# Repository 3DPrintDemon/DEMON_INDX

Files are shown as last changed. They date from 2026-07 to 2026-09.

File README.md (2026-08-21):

# INDX Wiki

> The community knowledge base for the Bondtech INDX, an induction-based automatic tool changer for open-platform XY-head 3D printers.

---

## Table of Contents

**Part 1: What is INDX?**

1. [What is INDX?](#what-is-indx)
2. [How It Works](#how-it-works)
3. [Kits & What's in the Box](#kits--whats-in-the-box)
4. [Supported Printers](#supported-printers)
5. [Technical Specifications](#technical-specifications)
   - [Part Cooling](#part-cooling)

**Part 2: Getting Started**

6. [Requirements & Preparation](#requirements--preparation)
7. [Installation](#installation)
   - [Hardware Installation](#hardware-installation)
   - [Firmware Configuration](#firmware-configuration)
     - [Klipper / Kalico](#klipper)
       - [INDX macro files](#indx-macro-files)
       - [Required Klipper sections](#required-klipper-sections)
       - [Load cell probe](#load-cell-probe)
       - [Automated dock X measurement](#automated-dock-x-measurement-built-in)
       - [Homing override](#homing-order-important)
     - [RRF (RepRapFirmware)](#rrf-reprapfirmware)
   - [Initial Startup](#initial-startup)

**Part 3: Configuration**

8. [Configuration](#configuration)
   - [Dock Position Calibration](#dock-position-calibration)
     - [Finding dock_y](#finding-dock_y-y-fully-seated-position)
     - [Finding dock_x](#finding-dock_x-x-tool-centre)
   - [Tool Offsets](#tool-offsets)
     - [Method 1: Print and adjust](#method-1-print-and-adjust-free-no-extra-hardware)
     - [Method 2: Nudge](#method-2-nudge-automatic-requires-small-hardware)
     - [Method 3: Nozzle camera + CAL_01/02/03](#method-3-nozzle-camera-most-precise-xy-higher-cost)
     - [Z offset: CAL_Z](#z-offset-calibration)
   - [Temperature & Induction Settings](#temperature--induction-settings)
   - [Speed & Acceleration](#speed--acceleration)

**Part 4: Day-to-day Use**

9. [Using INDX](#using-indx)
   - [Loading Filament into Tools](#loading-filament-into-tools)
   - [Performing Tool Changes](#performing-tool-changes)
   - [Slicer Setup](#slicer-setup)

**Part 5: Designing for INDX**

10. [Designing for INDX](#designing-for-indx)
    - [Dock Design](#dock-design)
    - [Part Cooling (custom)](#part-cooling-1)
    - [CAD Files & Templates](#cad-files--templates)

**Part 6: Maintenance, Support & Community**

11. [Maintenance](#maintenance)
    - [Nozzle clog: cold pull procedure](#nozzle-clog-cold-pull-procedure)
12. [Troubleshooting](#troubleshooting)
13. [FAQ](#faq)
14. [Community & Contributing](#community--contributing)

---

**Part 1: What is INDX?**

---

## What is INDX?

INDX (INduction Dynamic eXtruder) is Bondtech's automatic tool-changer system for FDM 3D printers. It enables printing with multiple materials, colors, or nozzle sizes in a single print, with near-zero purge waste and tool changes in around 14 seconds. Run two tools or ten; scale your setup as far as your build space allows.

Unlike filament-switcher systems, INDX is a true tool changer: each tool carries its own filament directly. There is no shared filament path and no purge block required.

Unlike traditional mechanical tool changers, INDX uses wireless induction heating, so the passive tools contain **no wires, no heaters, no thermistors, and no electronics**. This makes each tool dramatically cheaper and mechanically simpler.

INDX is sold by Bondtech as a **Development Kit** for open CoreXY printers. Prusa Research has built an official first-party integration for the **CORE One** and **CORE One L**, sold directly through Prusa.

| | INDX Development Kit | Prusa CORE One / CORE One L |
|---|---|---|
| **Sold by** | Bondtech ([bondtech.se](https://www.bondtech.se)) | Prusa Research ([prusa3d.com](https://www.prusa3d.com)) |
| **For** | Most CoreXY printers with open firmware | Prusa CORE One / CORE One L |
| **Setup** | Self-managed (community-supported) | Plug-and-play |
| **Smart Head** | See [bondtech.se](https://www.bondtech.se) | See [prusa3d.com](https://www.prusa3d.com/applications/prusa-3d-printers-with-bondtech-indx_243519/) |
| **Passive Tools** | See [bondtech.se](https://www.bondtech.se) | See [prusa3d.com](https://www.prusa3d.com/applications/prusa-3d-printers-with-bondtech-indx_243519/) |

This wiki focuses on the **INDX Development Kit** and community integrations. For the Prusa integration, refer to [Prusa's documentation](https://www.prusa3d.com/applications/prusa-3d-printers-with-bondtech-indx_243519/).

---

## How It Works

INDX is built around two components: a single active **Smart Head** that stays on the gantry, and a set of interchangeable **Thin Passive Tools** parked in a dock.

### Smart Head

The single active unit that travels on the gantry. Contains all expensive and active components:

- **Induction coil (IN)**: wirelessly heats the nozzle of whichever passive tool is currently mounted on the Smart Head.
- **IR thermopile sensor**: reads nozzle temperature without physical contact. Also reports ambient temperature and nozzle surround temperature for monitoring.
- **Dynamic eXtruder (DX)**: self-adjusting dual-drive extruder with automatic tension mechanism.
- **Load cell**: used for sensing tool/nozzle touch.
- All wiring, electronics, and motion stays here; nothing transfers to the passive tools

### Thin Passive Tools

Interchangeable tools parked in a dock within reach of the gantry. Each tool contains a filament path and a specially designed nozzle, and nothing else. No wires, no heaters, no thermistors, no electronics. Heat is delivered wirelessly by the Smart Head's induction coil when the tool is picked up; the tool cools passively when deposited back in the dock.

Two variants are available, both built from steel:

- **CHT (Core Heating Technology)**: splits filament into three strands internally for faster melting and higher flow rates. The standard choice for most materials except abrasive materials. Available in common sizes.
- **Standard (non-CHT)**: straight-through melt zone with lower back-pressure, optimized for soft flexible filaments (TPU, TPE).

Tools are held in the Smart Head by a high-precision **Maxwell coupling** (a 3-point kinematic coupling that self-aligns the tool to the exact same position every time it is picked up), ensuring micron-level repeatability on every tool change. In practice this means you calibrate your tool offsets once, and they stay correct across thousands of tool changes.

### Tool Change Sequence

1. Smart Head moves to the dock and deposits the current tool
2. Smart Head picks up the next tool
3. Induction coil heats the new nozzle to printing temperature (~4-10 seconds)
4. Printing resumes

**Total tool change time: ~14 seconds**, depending on temperature delta, priming, and travel distance.

Because every material runs in its own dedicated nozzle, there is no cross-contamination between materials; purging is not required. The only material used after a tool change is a small **prime** at the start of printing: when a nozzle heats up, the filament in the melt zone re-melts and pressure needs to be rebuilt before extrusion is consistent. Priming pushes a small amount of filament through to establish that pressure, ensuring the first line of print is correctly extruded. Because each tool also cools passively when separated from the Smart Head, oozing is minimal.

---

## Kits & What's in the Box

### Development Kit

The INDX Development Kit comes as a **base kit** (the core hardware you need to get started) plus **tools** and **accessories** you choose to match your printer and setup.

#### What's in the box

Every Development Kit includes:

| Component | Description |
| --- | --- |
| **Bondtech INDX Smart Head** | The active unit: induction coil, contactless IR temperature sensor, DX extruder, and all electronics. One per printer. **Does not include a Thin Passive Tool**; tools are ordered separately. |
| **Bondtech INDX Link Board** | USB/CAN bridge between your host computer and the Smart Head. Includes 330 mm AWG18 power cables with horseshoe connectors for PSU screw terminals. A USB cable from the Link Board to your host is not included; see [Link Board](#link-board) for requirements. |
| **Crimp & connector kit** | Crimps and connectors for terminating accessories to the Bondtech INDX PCB: part cooling fan, LED, endstop, and USB devices. |

#### Tools

Thin Passive Tools are the interchangeable tool heads that do the actual printing. Choose quantity, nozzle type, and nozzle size when ordering. You need at least one tool to print, and one per material or color you want to run simultaneously.

| Option | Nozzle sizes | Best for |
| --- | --- | --- |
| **CHT (Core Heating Technology)** | 0.4 / 0.5 / 0.6 / 0.8 / 1.0mm | Most materials: PLA, PETG, ABS, ASA, TPU, TPE, PVA, BVOH, HIPS, PC, Nylon, PP, PBT, unfilled PC blends, and other non-abrasive filaments |
| **Standard (non-CHT)** | 0.25 / 0.4mm | Flexible filaments (TPU, TPE) and sensitive composites |

See [Thin Passive Tools](#thin-passive-tools) in the Technical Specifications for full details on each variant.

#### Accessories

Select the accessories that match your printer when ordering:

| Accessory | Options | Notes |
| --- | --- | ----- |
| **Bondtech INDX Link Cable** | Choose length | XT30 2+2 cable (24V, GND, CAN+, CAN−) with a shield connected to GND on the Link Board, from the Link Board to the Smart Head. Red/black wires carry power, yellow/white carry CAN H/L. Choose the length that fits your wiring run. See note below. |
| **Tool Dock** | Pre-made SLS hardware or STL/STEP files | Bondtech sells ready-made docks for common Makerbeam/1515 extrusion. Or download the files and print your own. |
| **X-Carriage adapter** | MGN12H option for 6mm belts, or download files | Required to mount the Smart Head to your carriage. Available for common CoreXY standards; check the shop or download from GitHub. |

> **What is CAN bus?** CAN bus is a communication standard that lets multiple devices share a single cable. You don't need to understand the protocol in depth; the Link Board handles it for you. In practice it means the Smart Head connects to the Link Board via just one 4-wire cable (carrying both power and data) instead of the bundle of wires a conventional toolhead needs. CAN is currently only supported on RRF; USB is used for Klipper/Kalico.
>
> **Choosing cable length:** Measure the wiring run from your Link Board mounting location to the Smart Head along the actual path the cable will travel (over the gantry, not straight-line). Add some slack. When in doubt, order longer. A cable that is too short cannot be extended, and excess length can be coiled and managed.

> **Integration note:** The Development Kit does not include a pre-configured printer profile or plug-and-play setup. You are responsible for integrating INDX with your printer's firmware and mechanics. The community provides configs and guides for common platforms; see [Supported Printers](#supported-printers) and [Community & Contributing](#community--contributing).

---

## Supported Printers

### First-party integrations

Prusa Research has built an official first-party integration for their CoreXY printers. These are sold and supported directly by Prusa, not through the INDX Development Kit.

| Printer | Status | Notes |
| --- | --- | ----- |
| Prusa CORE One | Available | Sold by Prusa Research. Plug-and-play. Supports up to 8 tools. See [prusa3d.com](https://www.prusa3d.com/applications/prusa-3d-printers-with-bondtech-indx_243519/) for details. |
| Prusa CORE One L | Coming later | First-party Prusa integration, availability timeline TBD. Supports up to 8 tools. |

### Officially supported integrations

Beyond the first-party Prusa integration, Bondtech officially supports a small set of community-built integrations for specific printers. Each comes with ready-to-print parts and the installation files needed to mount INDX on that machine. Download them from the links below.

| Printer | Designer | Files |
| --- | --- | ----- |
| Sovol SV08 OG & SV08 Max | 3DPrintDemon | [Printables](https://www.printables.com/model/1771164-official-indx-sovol-sv08-og-sv08-max-integrations) |
| Voron Trident R2 | Steve — Voron team, designer of the Trident | [Printables](https://www.printables.com/model/1761163-trident-r2-bondtech-indx-mods) |

### Community integrations

INDX runs on a wide range of CoreXY printers, far more than Bondtech could ever test and support directly. What makes that possible is community members who've done the integration work on their own printer and shared what they learned. Every config in the repo started with someone doing it for the first time.

> **What does "community" status mean?** The hardware works on that printer, but the integration guide comes from the community, not Bondtech. Some printers already have complete, verified configs on GitHub; check the repo first. Others are earlier stage. The [Bondtech Discord](https://discord.gg/XDX9jDXN6e) has channels for specific printers, which is a good place to find others running the same platform and see how far along the integration is.

| Printer | Status | Notes |
| --- | --- | ----- |
| Voron 2.4 | Community | |
| Voron Trident | Community | Trident R2 has an [officially supported integration](#officially-supported-integrations) |
| RatRig V-Core | Community | |
| Sovol | Community | SV08 OG / SV08 Max have an [officially supported integration](#officially-supported-integrations) |
| Custom CoreXY | Community | Any CoreXY with open firmware; see [Requirements](#requirements--preparation) |

**Your printer isn't listed?** If you've got INDX running on it, that integration belongs here. Submit a pull request on [github.com/BondtechAB/INDX](https://github.com/BondtechAB/INDX) and you'll save the next person hours of work. See [Contributing a printer integration](#contributing-a-printer-integration) for what to include.

---

## Technical Specifications

*Specifications are preliminary and subject to change.*

### Smart Head

| Specification | Value |
| --- | ----- |
| Maximum operating voltage | 24V |
| Maximum nozzle temperature | 300°C |
| Maximum ambient operating temperature | 60°C |
| Flow rate | 40mm³/s *(measured at 220°C with 25°C ambient; lower rates achievable depending on nozzle size)* |
| Nozzle heat-up time | ~4-8 seconds |
| Tool change time | ~14 seconds *(highly dependent on temperature, priming, and travel distance)* |
| Power consumption | ~60W |
| Tool change mechanism | Maxwell coupling (3-point kinematic) |
| Heater type | Induction coil |
| Temperature sensor | Wireless & contactless IR thermopile |
| Nozzle sensor | Load cell (bi-directional) |
| Extrusion system | Direct Drive |
| Filament pre-tension | Self-adjusting (DX extruder, dual-drive with automatic tensioning) |
| Extruder chassis material | Aluminium |
| Cowling material | SLS-printed PA12 |
| Minimum tool center-to-center distance | 34mm bare; **41mm** with Bondtech part cooling solutions |
| Weight | 345g *(including one tool)* |
| Dimensions | See [reference geometry](#cad-files--templates) |

### Part Cooling

INDX uses a modular part cooling system. Cooling solutions snap onto the outside of the Smart Head cowlings, making it easy to swap between setups without tools. Three options are supported:

| Option | Description |
| --- | --- |
| **Dual 40×10 fans** | Two radial blower fans mounted symmetrically for balanced airflow around the nozzle |
| **CPAP** | High-flow airflow from a remote CPAP blower unit, routed via a flexible tube to the Smart Head, keeping weight off the gantry |

The right choice depends on your materials and print speed requirements. The dual 40×10 connect to the part cooling fan output on the Bondtech INDX PCB. The CPAP blower is a remote unit mounted elsewhere on the printer and connects to your main board instead; only the airflow tube routes to the Smart Head.

Printable ducts for both options are available in [CAD Files & Templates](#cad-files--templates).

### Bondtech INDX PCB

The Bondtech INDX PCB is mounted inside the Smart Head and is the central electronics board for the system.

**Electronics**

| Specification | Value |
| --- | ----- |
| Stepper driver | TMC2240 |
| Stepper run current | 0.6A |
| Extruder rotation distance | 5.7mm |
| Built-in accelerometer | LIS2DW |
| Built-in rotary encoder | AS5047D (magnetic) |
| Built-in load cell | *(specifications to be confirmed)* |

**Connectors**

| Connector | Pins | Notes |
| --- | ---- | ----- |
| Motor | Coil A+, Coil A−, Coil B+, Coil B− | DX extruder stepper motor |
| Fan | TACHO, FAN+, GND | Supports tachometer feedback |
| LED | 5V (VBUS), NP OUT, GND | NeoPixel compatible |
| Endstop | 3V3, SIGNAL, GND | 3.3V logic level |
| USB | VBUS, DP+, DP−, GND, GND | Supports accessories such as camera or Beacon probe scanner. **The DP+/DP− silkscreen is swapped — see [USB data pins](#usb-data-pins-are-swapped)** |
| CAN termination jumper | — | Enable/disable CAN bus termination |
| CAN Reset jumper | — | Puts the board into DFU mode for firmware flashing; remove after flashing |
| Communication switch | CAN / USB | Selects between CAN-FD and USB communication modes; must match the switch position on the Link Board |

**Status LEDs**

| Label | Colour | Meaning |
| ----- | --- | --- |
| VIN | Blue | 24V power present |
| 3V3 | Green | 3.3V onboard regulator active |
| ACTIVITY | Green | CAN-FD bus activity (other than regular time-sync messages) |
| STATUS | Red | Flashes at ~1Hz in sync with the main board = CAN time sync OK; rapid continuous flashing = no CAN sync; startup error codes (see table below) |

On first boot or after a failed flash, the STATUS LED may flash a startup error code rather than the normal 1Hz pattern. The pattern is: slow blinks (group 1) pause, then fast blinks (group 2). If this happens, reflash the firmware.

**Startup error codes**

| Error | Slow blinks | Fast blinks | Description |
| ----- | --- | --- | --- |
| ErrorTempMin | 1 | 1 | Measured temperature too low |
| ErrorTempMax | 1 | 2 | Measured temperature too high |
| ErrorTempAmbientMin | 1 | 3 | Ambient temperature too low |
| ErrorTempAmbientMax | 1 | 4 | Ambient temperature too high |
| ErrorTempDiff | 1 | 5 | Requested temperature differs significantly from measured temperature |
| ErrorHeatMax | 2 | 1 | Heater on at max power for too long |
| ErrorHeatInput | 2 | 2 | Heater enable request active for too long |
| ErrorInternalTemp | 5 | 3 | IR sensor self-test failed at boot |
| ErrorInternalUart | 5 | 4 | Internal UART fault |
| ErrorInternalEnable | 5 | 5 | Internal enable fault |

**Front INDX LED states**

The Smart Head uses a NeoPixel-compatible LED array on the front face to communicate its current state during normal operation. These are the same LEDs that display startup error codes.

| State | Colour | Pattern |
| ----- | --- | --- |
| Heating | Amber (RGB 255, 191, 0) | Breathing at 0.5 Hz (sine); brightness starts at 0 and increases as temperature approaches target |
| Cold / at ambient | Green | Solid |
| At target temperature | Amber | Solid |
| Cooling down from hot | Blue | Solid |
| DFU (firmware update) mode | Blue | Blinking |
| Load cell transient (filament gripped) | Purple | Single fast flash (~200 ms), then returns to previous state; effect is suppressed while the stepper motor is energised |

**FFC cable warning**

The Smart Head contains two PCBs (INDX VF PCB and INDX MCU PCB) connected by 20-way FFC (Flexible Flat Cable) connectors. If you ever need to disconnect and reconnect them during servicing:

- Insert the cable straight; inserting at an angle is easy to do and will short pins. Powering up with a shorted FFC will likely damage the board.
- The latch direction on the INDX MCU PCB FFCs is counter-intuitive: the latch is **unlocked when up**. After inserting the cable, push the latch **down toward the PCB** to lock it.

### Link Board

Bondtech INDX Link Board

The Link Board is a required component of every INDX Development Kit setup. It sits between your host computer and the Smart Head, acting as the USB/CAN bridge and providing several protection features that make the connection stable and safe.

**Why the Link Board is required**

The Link Board caps USB communication speed to **12 Mbps (Full Speed)**. While this is lower than the theoretical USB 2.0 maximum, it is intentional: Full Speed USB is dramatically more stable in electrically noisy printer environments than High Speed (480 Mbps). In practice this means fewer dropouts and disconnects, and a much more reliable connection to the Smart Head.

**Protection features**

| Feature | What it does |
| --- | --- |
| **USB isolator** | Electrically isolates the Smart Head from your host computer. Any electrical fault or noise on the printer side cannot travel back through the USB cable to your Raspberry Pi or PC. |
| **Reverse polarity protection** | Prevents damage if the 24V power input is connected with reversed polarity. |
| **4A fuse** | Protects the power input. If something goes wrong on the 24V side, the fuse blows before damage can propagate further. |

**Communication switch**

The Link Board has a switch to select between **USB** and **CAN** communication modes. This must match the switch position on the INDX MCU PCB inside the Smart Head — both boards must be set to the same mode, or the connection will not work. See [Switch configuration](#3-wiring) for reference images showing the correct switch positions on the Smart Head side.

**USB cable (not included)**

A USB cable from the Link Board to your host computer is not included and must be sourced separately. Requirements:

- **Data cable, not a charge-only cable.** Charge-only cables omit the data lines entirely and will not work. Verify the cable is rated for data transfer before using it.
- **Correct impedance.** The cable must meet USB signal integrity requirements. Cheap or poorly made cables can cause dropouts even at Full Speed. Use a cable from a reputable brand.
- **Total USB run ≤ 2 meters.** The combined length of your USB cable (host to Link Board) and your INDX Link cable (Link Board to Smart Head) must not exceed 2 meters. Plan your cable routing and Link cable length selection with this in mind.

**Specifications**

| Specification | Value |
| --- | ----- |
| Host connection | USB-C |
| Printer-side connection | Link cable to Bondtech INDX PCB |
| Input power | 24V + GND from PSU |
| Included power cables | AWG18, 330mm, horseshoe connectors for PSU screw terminals |
| USB speed | 12 Mbps (Full Speed) |
| Fuse rating | 4A |
| Max total USB run | 2 meters (USB cable + Link cable combined) |

### Thin Passive Tools

All Thin Passive Tools are built from steel, contain no electronics or wiring, and use induction heating via the Smart Head. Two variants are available:

**CHT (Core Heating Technology): Standard choice for most materials**

Uses Bondtech's patented CHT internal geometry, which splits filament into three thinner strands for faster melting and higher flow rates. Recommended for PLA, PETG, ABS, ASA, TPU, TPE, PVA, BVOH, HIPS, PC, Nylon, PP, PBT, unfilled PC blends, and other non-abrasive filaments.
Not recommended for soft flexible filaments.

| Specification | Value |
| --- | ----- |
| Available nozzle sizes | 0.4 / 0.5 / 0.6 / 0.8 / 1.0mm |
| Material | Steel |
| Compatible filament diameter | 1.75mm |
| Maximum nozzle temperature | 300°C |
| Electronics | None |
| Weight | 25g |

**Standard (non-CHT): For flexible and sensitive materials**

Uses a straight-through melt zone with minimal back-pressure, specifically optimized for soft flexible filaments (TPU, TPE) and sensitive composites. Built to the same steel standard.

| Specification | Value |
| --- | ----- |
| Available nozzle sizes | 0.25 / 0.4mm |
| Material | Steel |
| Compatible filament diameter | 1.75mm |
| Maximum nozzle temperature | 300°C |
| Electronics | None |
| Weight | 25g |

---

**Part 2: Getting Started**

---

## Requirements & Preparation

If you've built a Voron or a similar CoreXY printer from scratch, you have the skills needed to install INDX. The process involves editing Klipper config files, SSH access to your host computer, and careful mechanical alignment. Nothing beyond what a first-time Voron builder will have already done.

### Printer Requirements

For the Development Kit, your printer must meet these minimum requirements:

- **Motion system:** CoreXY, H-bot, Markforged, Cartesian XY-head, or similar. Supported: any motion system where the toolhead moves in XY and Z is handled by the bed or gantry — i.e. CoreXY (not cross-gantry), H-bot, Markforged, and independent-axis Cartesian (XY-head, e.g. Ender 5). Not supported: bed-slinger Cartesian (XZ-head), where the bed moves in Y, or Positron-style machines.
- **Firmware:** Kalico (recommended — native INDX support built in), Klipper, or RepRap Firmware (RRF)
- **Gantry clearance:** 50mm X, 44mm Y. Total toolhead height is ~152mm including strain relief. Additional clearance is required for umbilical and filament management.
- **Dock mounting area:** Each dock is ~70mm tall, 28.5mm wide (X), and 25mm deep (Y). Minimum tool center-to-center spacing is 34mm bare, or 41mm when using the Bondtech part cooling solutions.
- **Wiring:** 24V from the PSU to the Link Board (AWG18 horseshoe-connector cables included). Host computer to Link Board via USB-C or CAN. Link Board to Smart Head via INDX Link Cable (XT30 2+2, carries 24V, GND, CAN+/−, and shield).
- **Print volume impact:** Depends on printer geometry. Printers with sufficient Y overtravel may lose nothing. With a well-designed integration the worst case is 28.5mm of Y travel; avoid designs that exceed this.

### Electrical Requirements

INDX uses two boards: the **Bondtech INDX PCB** (inside the Smart Head) and the **INDX Link Board**.

**Bondtech INDX PCB**

The Bondtech INDX PCB is the central electronics board inside the Smart Head. It consists of two parts connected internally:

- **INDX VF PCB**: handles induction heating, contactless IR temperature sensing, and the heatsink fan
- **INDX MCU PCB**: handles all processing and communication: extruder motor control, accelerometer, load cell, CAN-FD communication, and the external connectors

All electronics are pre-installed inside the Smart Head; no internal wiring required. The Smart Head connects to the Link Board via a single INDX Link Cable (24V, GND, CAN H/DP+, CAN L/DN−, shield to GND) and exposes the following connectors:

- **Motor**: 4-pin, drives the DX extruder (TMC2240 driver). Pin 1 Coil A+, Pin 2 Coil A−, Pin 3 Coil B+, Pin 4 Coil B−
- **Endstop**: 3-pin, 3.3V logic level. Pin 1 3V3, Pin 2 SIGNAL, Pin 3 GND
- **Fan**: 3-pin, supports tachometer feedback. Pin 1 TACHO, Pin 2 FAN+ (PWM 24V), Pin 3 GND
- **LED**: 3-pin NeoPixel. Pin 1 5V (VBUS), Pin 2 NP OUT, Pin 3 GND
- **USB**: 5-pin, supports accessories such as a camera or Beacon probe scanner. Pin 1 VBUS (5V), Pin 2 DP+, Pin 3 DP−, Pin 4 GND, Pin 5 GND. **The DP+ and DP− labels are swapped relative to the actual signals — see [USB data pins](#usb-data-pins-are-swapped) before wiring anything to this connector**
- **Built-in accelerometer**: for resonance measurement and automatic input shaper calibration in Klipper
- **CAN termination jumper**: fitting the jumper enables the 120 Ω end-of-line termination resistor. Fit only on boards at the physical ends of the CAN bus.
- **CAN reset jumper**: Klipper: short the jumper to enter DFU mode for flashing. RRF: fit the jumper for CAN reset (also resets the CAN address). See the [Duet INDX Toolboard documentation](https://docs.duet3d.com/en/Duet3D_hardware/Duet_3_family/INDX_Toolboard).
- **Status LEDs**: 3V3, VIN, STATUS, ACTIVITY

Induction heating and contactless IR temperature sensing are handled internally by the INDX VF PCB; no additional wiring or configuration needed.

Bondtech INDX PCB pinout

##### USB data pins are swapped

> ⚠️ **The DP+ and DP− labels on the USB connector are wrong.** The pin marked **DP+ is electrically DP−**, and the pin marked **DP− is electrically DP+**. This applies to the silkscreen, the pinout image above, and the pin tables in this document. Wire by function, not by label.

So a USB accessory connects like this:

| INDX pin | Marked | Actually is | Connect to |
| --- | --- | --- | --- |
| 1 | VBUS | VBUS (5V) | 5V |
| 2 | DP+ | **DP−** | DATA − |
| 3 | DP− | **DP+** | DATA + |
| 4 | GND | GND | Ground |
| 5 | GND | GND | — |

For a Cartographer V4, whose own wiring guide lists black = Ground, green = DATA +, white = DATA −, that means green goes to the pin marked DP− and white goes to the pin marked DP+. Two users independently found that wiring by the printed labels fails to enumerate and that swapping the pair works.

If a USB accessory isn't detected at all, this is the first thing to check.

**Klipper pin → port mapping** (not exposed in RRF)

| Function | Port(s) |
| --- | --- |
| Motor | STEP `PB12` · DIR `PB23` · ENN `PB4` · CS `PA10` · SPI1 SCLK `PA5` / MOSI `PA4` / MISO `PA7` |
| Endstop | `PA9` |
| Part cooling fan | FAN `PA1` · TACHO `PA0` |
| Heatsink fan | FAN0 `PA21` · TACHO `PA20` |
| Neopixel | `PA8` |
| Eddy scanner | ldc_int `PB10` · ldc_clk `PB11` · temp_ldc `PB9` |

**Link Board**

The Link Board is required and bridges your host computer to the Smart Head. For full details on protection features, the communication switch, and USB cable requirements, see [Link Board](#link-board) in the Technical Specifications.

For wiring purposes:

- Requires **24V and GND** from your printer's power supply; connect using the included power cables (AWG18, 330 mm, pre-terminated with horseshoe connectors for screw terminal PSUs)
- Connects to the Smart Head via the INDX Link Cable
- Connects to your host computer via USB (cable not included — see [Link Board](#link-board) for requirements)
- The communication switch on the Link Board must match the switch on the INDX MCU PCB; both must be set to the same mode

**Power**

- The system runs on **24V**
- The Link Board is powered by a direct 24V/GND connection from your PSU
- Power is then passed through the Link cable (24V, GND, CAN+/D+, CAN−/D-) from the Link Board to the Smart Head; no additional PSU connection needed at the Smart Head

**Mainboard compatibility**

- Works with any printer running a Raspberry Pi, similar host computer or Duet board
- The Link Board connects to the host via CAN/USB; the host handles CAN/USB communication to the Bondtech INDX PCB

### Software Requirements

- **Kalico (recommended):** native INDX support is built in — nothing to install on the host, and the MCU firmware ships with Kalico. See [Firmware Configuration](#klipper).
- **Klipper (mainline):** add the [`indx_klipper`](https://github.com/BondtechAB/indx_klipper) module (installed with its `install.sh`), which brings the same INDX support to a stock Klipper install. See [Firmware Configuration](#klipper).
- RRF: RepRapFirmware **3.7.0-alpha (2026-02-10) or later**, required on both the main board and the Bondtech INDX PCB.
- Slicer: Any slicer with multi-filament or multi-color support

### Tools Required

| Tool | Use |
| ---- | --- |
| Hex keys | Smart Head, X-carriage adapter, and dock mounting |
| Crimping tool | Optional; only needed if connecting accessories (fan, LED, endstop, or USB devices) to the Bondtech INDX PCB |

### Skills Assumed

- Editing Klipper config files (`.cfg` syntax, adding sections, restarting Klipper)
- SSH access to your host computer (the [Connect via SSH](#connect-to-your-printer-via-ssh) section covers this if you need a refresher)
- Crimping JST and similar connectors

### What to Have Ready Before Starting

- A working printer, homed, printing, and confirmed stable before you begin
- Kalico (or Klipper / RRF) installed and running on your host computer
- SSH access to your host computer confirmed
- Spool holders and filament routing planned for the number of tools you intend to run

---

## Installation

> **Note:** These are general installation guidelines using the Bondtech-sold hardware as an example. Because INDX works across many different CoreXY printers, exact details (screw sizes, adapter geometry, carriage type, dock placement) will vary by printer. For printer-specific integration guides, check the [github.com/BondtechAB/INDX](https://github.com/BondtechAB/INDX) repository and the community resources in [Community & Contributing](#community--contributing).

### Hardware Installation

#### 1. Install the Smart Head

The Smart Head replaces your printer's existing toolhead entirely. It mounts to the X-axis carriage using a two-part system:

1. **X-carriage adapter**: bolts onto your carriage
2. **Smart Head**: attaches to the X-carriage adapter with 4 bolts

**X-carriage adapters** are available in two ways:

| Source | Material | Notes |
| --- | --- | --- |
| Bondtech (shop) | SLS-printed Nylon 12 GF | Common MGN12 carriage options available to purchase |
| GitHub / community | User-printed | STL/STEP files on [github.com/BondtechAB/INDX](https://github.com/BondtechAB/INDX); print your own for less common setups |

If your carriage configuration isn't covered by Bondtech's sold options, check the GitHub repo for a community-contributed adapter or print your own from the provided files. A printable MGN12H adapter (6mm belts) is available in [CAD Files & Templates](#cad-files--templates). Community-made X-carriage designs that meet quality standards will be included in the official repo. If you're designing your own, see [CAD Files & Templates](#cad-files--templates) for the reference geometry files.

> **Before you start:** Remove your existing hotend, part cooling fan, and any toolhead PCB or wiring mounted on the carriage. The Smart Head replaces all of this.

**Step 1: Mount the X-carriage adapter to the carriage**

Route and attach the belts behind the X-carriage, then attach the X-carriage adapter to your carriage block using the screws specified for your adapter. Tighten firmly but do not overtighten.

INDX MGN12H adapter mounting to rail, exploded view

INDX MGN12H adapter mounted on rail

**Step 2: Place the Smart Head onto the adapter**

Slide the Smart Head onto the X-carriage adapter so the mounting faces are flush.

Smart Head placed on X-carriage adapter

**Step 3: Secure the Smart Head**

Fasten the Smart Head to the adapter using 4 screws as specified for your adapter. Tighten firmly but do not overtighten.

Smart Head secured, rear view

Smart Head fully installed, front view

The Smart Head is now installed on the carriage.

**Attach part cooling**

Part cooling solutions snap onto the outside of the Smart Head cowlings. Attach your chosen cooling solution now before mounting the dock.

**Installing the fan shroud clip**

The clip is the interface between a fan shroud and the Front Cover, and there is a left and a right one: [`INDX_Part_Cooling_Interface_left.stl`](CAD/STL/INDX_Part_Cooling_Interface_left.stl) and [`INDX_Part_Cooling_Interface_right.stl`](CAD/STL/INDX_Part_Cooling_Interface_right.stl). Print both before starting, and repeat these steps for each side.

1. Loosen the screw that holds the INDX Front Cover.

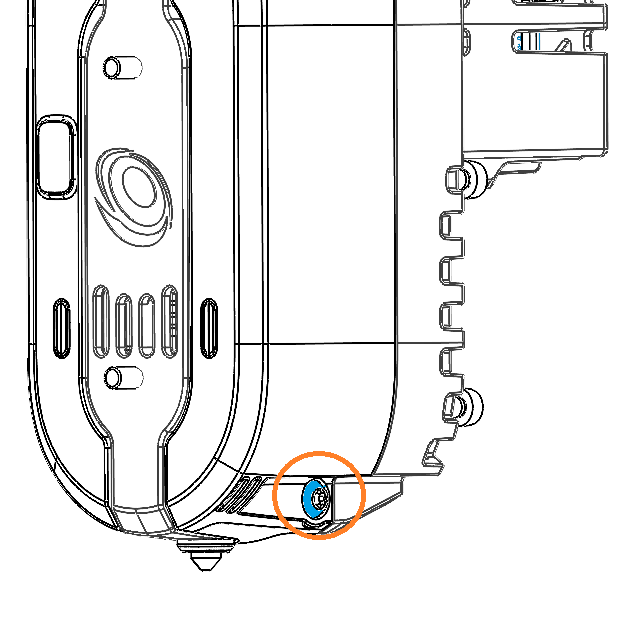
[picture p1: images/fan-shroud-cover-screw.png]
Loosen front cover screw
   

2. Use an M3×8 screw to secure the INDX Front Cover together with the fan shroud clip.

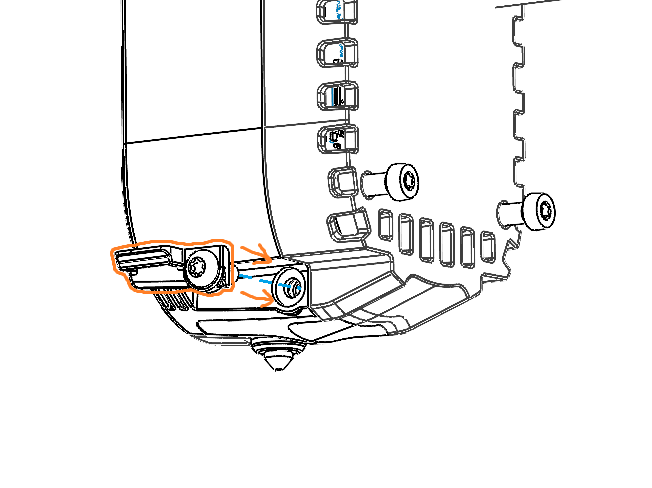
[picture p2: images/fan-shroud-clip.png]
Fan shroud clip installed
   

3. With the clip installed, attach the fan shroud to the Front Cover. The shroud has an upper tab that locates into a slot at the top of the Front Cover (highlighted in blue). Align the tab with the slot, then rotate the bottom of the shroud inward until it seats in position.

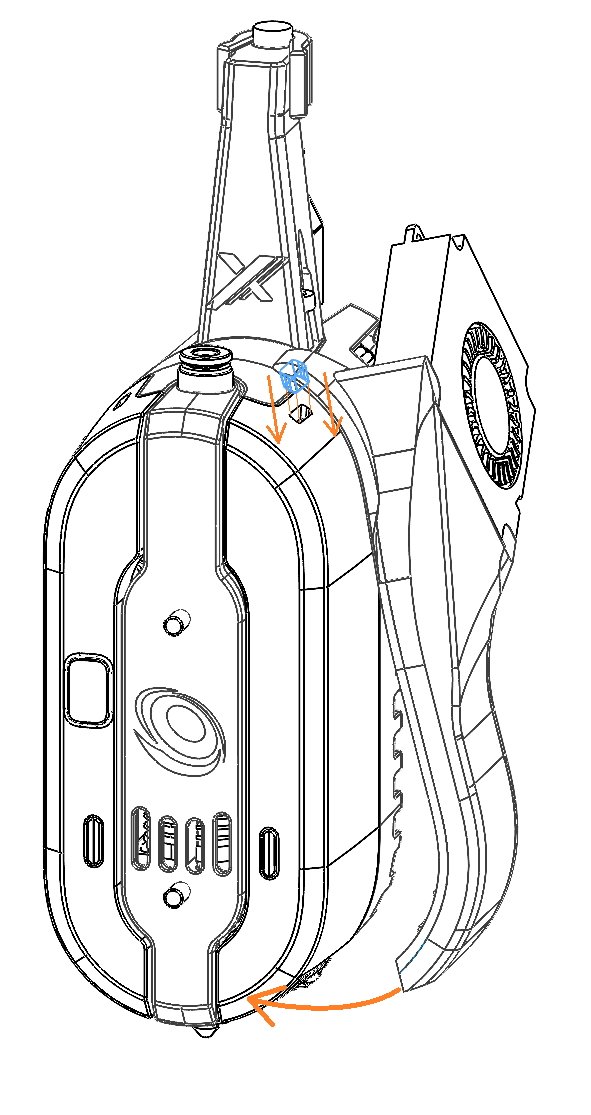
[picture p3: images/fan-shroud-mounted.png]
Fan shroud mounted
   

#### 2. Mount the Dock

The dock can be positioned anywhere within the gantry's travel range, but the Smart Head must be able to face the docked tools directly to pick them up. The right location depends on your printer's layout.

**Frame requirement**

The dock must be mounted to a rigid bar or frame element; the dock hardware alone cannot be free-standing. Most CoreXY printers have an extrusion or crossbar that works for this. If your printer does not have a suitable mounting point, you will need to add one before proceeding.

The Bondtech-sold dock hardware is designed to mount on **15×15 aluminium extrusion**. If you are printing your own dock from the GitHub files, design your mounting to suit your frame.

> ⚠️ **Critical:** The dock has strict positioning requirements that must be met for reliable tool changes. Incorrect placement will cause failed pickups. See the critical requirements below before mounting.

**Dock options:**

| Source | Type | Mounting |
| --- | --- | --- |
| Bondtech (shop) | SLS-printed Nylon 12 GF | Common options for 15×15 aluminium extrusion |
| GitHub | Reference design + community designs | Print yourself, or adapt for your frame |

Community-contributed dock designs will be added to [github.com/BondtechAB/INDX](https://github.com/BondtechAB/INDX) as they are developed. If you design a dock for an unlisted printer or frame, consider submitting it. See [Dock Design](#dock-design) for geometry constraints and design requirements before you start.

**Critical dock positioning requirements**

**Height**

The dock must be positioned so that a parked tool sits **2mm higher** than it does when held in the Smart Head. This offset is what allows the Smart Head to pick up and deposit tools cleanly.

Dock height reference: 2mm offset between docked and picked-up tool position

**Alignment method**

Use the printable alignment jig ([`INDX_Dock_calibration_tool.stl`](CAD/STL/INDX_Dock_calibration_tool.stl)) placed over the nozzle tool in the toolhead to set the correct height. The printer does not need to be powered on for this step; you are setting the physical dock height manually.
_Pro tip: you can also use the alignment jig to get exact X alignment of the docks, by moving your printhead to the desired X value before doing the steps below._

1. Place the printed alignment jig over the tool magnets while the tool is in the smart head.

   Alignment jig fitted over the tool magnets on the Smart Head

2. Loosen the bar holding screws in order to let it be adjusted up and down, then slide the smart head toward the tool dock and make sure the alignment jig enters the magnet holes smoothly without the smart head nodding from mechanical strain.

   Alignment jig entering the tool holder magnet holes in the dock

3. Secure the dock bar at that height

#### 3. Wiring

Wiring up the Smart Head is unusually simple for a toolhead. On a conventional setup, you're running individual wires for the heater cartridge, thermistor, hotend fan, stepper motor, and any probes or sensors, each terminated, routed, and managed separately. With INDX, all of that is internal: the induction coil, IR temperature sensor, and heatsink fan are all handled inside the Smart Head with no external connections required. The only cable you run to the Smart Head is a single INDX Link Cable, four wires carrying 24V power and data.

The included **Link Board** acts as the bridge between your host computer and the Smart Head. Your host computer connects to the Link Board via USB (cable not included — see [Link Board](#link-board) for requirements), the Link Board connects to the Smart Head via the INDX Link Cable, and the Link Board receives 24V power from the PSU via the included AWG18 cables. That's the entire wiring run.

**Overview of connections:**

```
24V PSU ──────────────────────────────────────────────┐
                                                       │ 24V + GND
Raspberry Pi / host computer                           ▼
    │                                             Link Board
    └── USB ──────────────────────────────────────────►│
                                                       │
                                                       └── Link cable (24V, GND, CAN H/DP+, CAN L/DN−) ──► Bondtech INDX PCB (inside Smart Head)
                                                                                                           │
                                                                                                           ├── Motor (Coil A+, Coil A−, Coil B+, Coil B−)
                                                                                                           ├── Fan (TACHO, FAN+, GND)
                                                                                                           ├── LED (5V, NP OUT, GND)
                                                                                                           ├── Endstop (3V3, SIGNAL, GND)
                                                                                                           └── USB (VBUS, DP+, DP−, GND, GND)
```

**Switch configuration**

Before connecting the Link cable, set the communication mode switches on **both boards** to match: the switch on the INDX MCU PCB inside the Smart Head, and the switch on the Link Board. Both must be set to the same mode or the connection will not work.

Set both switches to **CAN** if you are using RRF. Set both to **USB** if you are using Klipper or Kalico.

INDX MCU PCB switch set to CAN mode
*Switch set to CAN mode*

INDX MCU PCB switch set to USB mode
*Switch set to USB mode*

#### 4. Flash the Bondtech INDX PCB

The Bondtech INDX PCB needs to be flashed with the correct firmware before the Smart Head can communicate with your printer. The flashing process differs depending on your firmware; follow the section for your setup.

##### Klipper / Kalico

Flashing is done over SSH from your computer into the Raspberry Pi (or other host computer) running Kalico or Klipper.

**What you need**

- **PuTTY**: a free SSH client for Windows. Download it from [putty.org](https://www.putty.org/).
- Your printer's **IP address**: find this in your router's device list, or check the display on your host if it shows one. You can also use the hostname (e.g. `mainsailos.local` or `fluidd.local`) if your network supports it.

###### Connect to your printer via SSH

1. Open PuTTY
2. Enter your printer's IP address (or hostname) in the **Host Name** field
3. Make sure **Port** is set to `22` and **Connection type** is `SSH`
4. Click **Open**
5. Log in with your printer host credentials; the default username for most Klipper distributions is `pi` (Mainsail OS / FluiddPI) with the password you set during setup

You should now have a terminal prompt on your printer's host computer.

**Enter the bootloader**

Flashing happens while the Bondtech INDX PCB is in bootloader mode. If the board already has firmware, put it into the bootloader by fitting the **CAN RESET jumper** on the INDX MCU PCB while powering the board up. In bootloader mode the board enumerates on the host as a Microchip USB device (vendor `04d8`, product `e483`), identified as **"INDX Toolboard Bootloader"** by Bondtech AB. Confirm it is present with:

```bash
lsusb | grep 04d8:e483
```

**Kalico (recommended)**

Kalico ships with native INDX support built in — both the host module and the MCU firmware are part of the Kalico source tree, so there is nothing extra to install. Build and flash from your Kalico directory (usually `~/klipper`):

```bash
cd ~/klipper
KCONFIG_CONFIG=board_configs/bondtech_indx_usb.config make
KCONFIG_CONFIG=board_configs/bondtech_indx_usb.config make flash FLASH_DEVICE=04d8:e483
```

The `board_configs/bondtech_indx_usb.config` build config is included with Kalico. It preselects the SAME51 MCU, USB communication, and the INDX heater feature, so you don't need to run `make menuconfig`.

**Klipper (mainline)**

Mainline Klipper does not include INDX support. Add it with the `indx_klipper` module, then build and flash:

```bash
git clone https://github.com/BondtechAB/indx_klipper.git
cd indx_klipper
./install.sh /home/pi/klipper        # adjust the path to your Klipper install
make
make flash FLASH_DEVICE=04d8:e483
```

Once flashing is complete, remove the CAN RESET jumper (if you fitted one), power-cycle the Smart Head, and proceed to firmware configuration.

##### RRF (RepRapFirmware)

For RRF, flash and configure the Bondtech INDX PCB following the [Duet INDX Toolboard documentation](https://docs.duet3d.com/en/Duet3D_hardware/Duet_3_family/INDX_Toolboard).

#### 5. Load Passive Tools into the Dock

**Verify the Tool Dock Activator**

Before loading tools, check that the Tool Dock Activator is correctly installed. It is a small bracket mounted upright on the 15×15 mm aluminium extrusion using an M3×10 screw and an M3 nut. It must be perfectly vertical; this is the component that triggers the INDX latch mechanism during pickup.

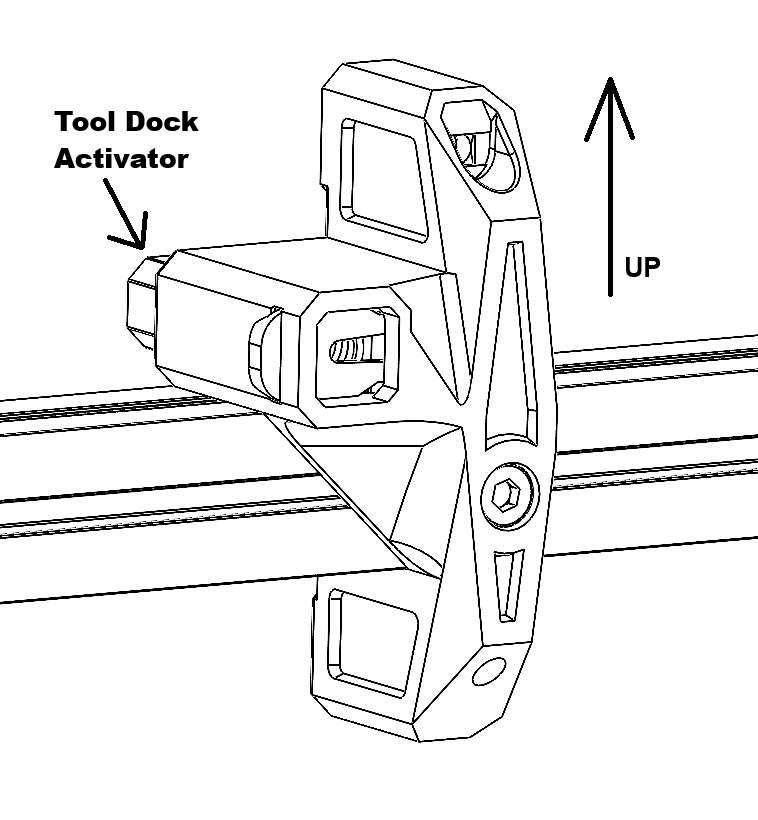
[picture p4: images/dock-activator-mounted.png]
Tool Dock Activator mounted on extrusion


Check that it is perpendicular to the extrusion:

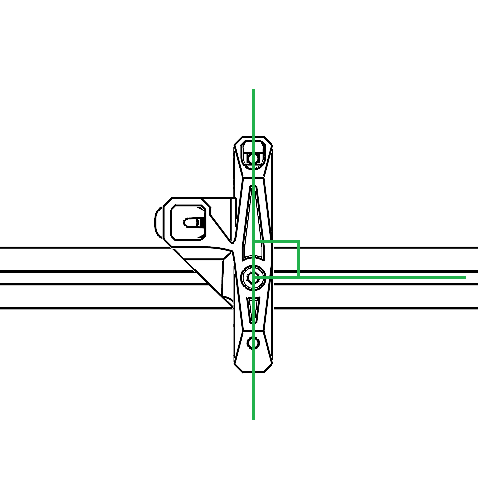
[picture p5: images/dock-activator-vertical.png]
Tool Dock Activator vertical alignment


**Load tools into the dock**

One passive tool fits in one dock position. Tools are retained by 3×8 mm bar magnets embedded in both the tool and the dock. The magnets naturally guide the tool into the correct orientation as you bring it close; follow the magnetic pull to seat it.

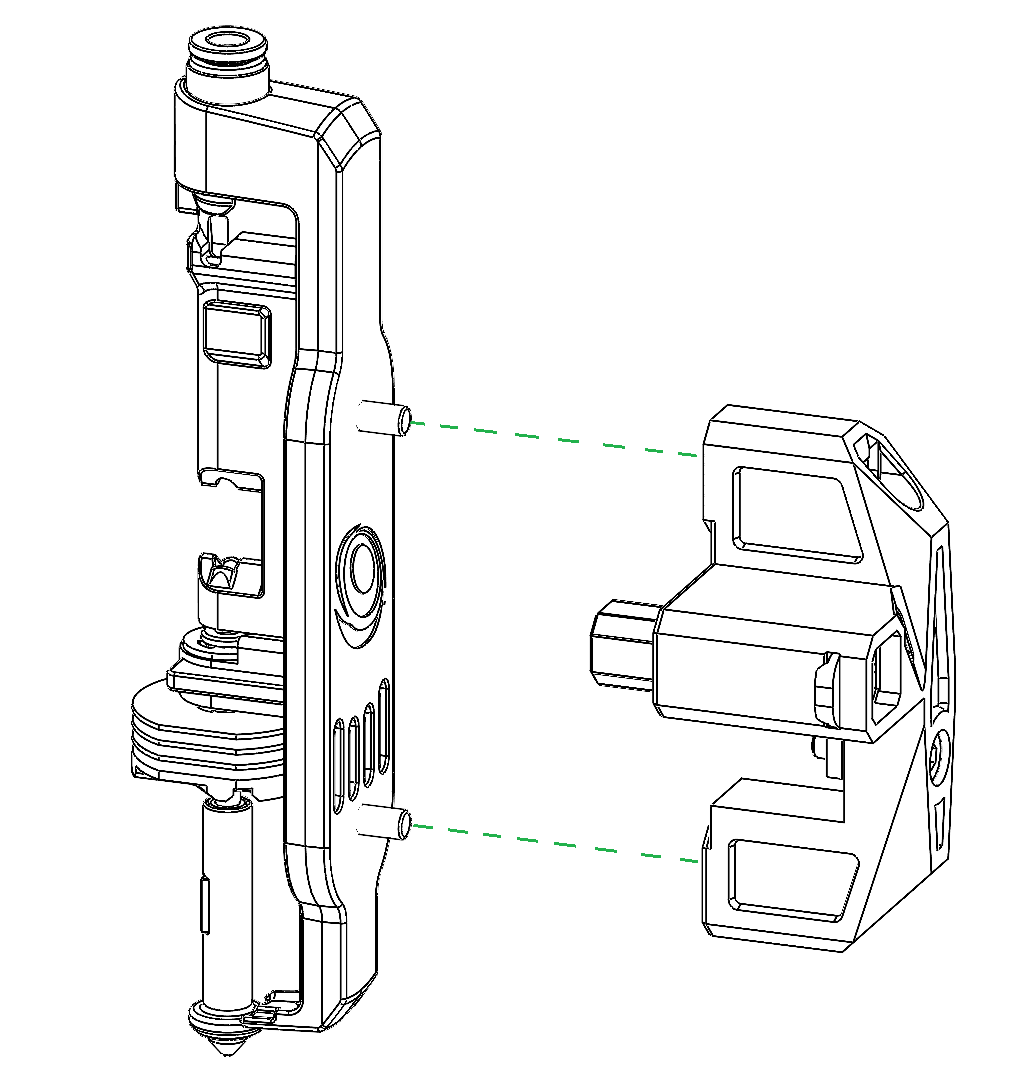
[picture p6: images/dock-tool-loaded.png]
Passive tool loaded in dock


> **Note:** You will set the exact dock position coordinates (`dock_y` and `t*_x`) during the calibration steps later. For now, just seat the tools; the INDX macros handle the rest once configured.

---

### Firmware Configuration

#### Klipper

INDX's host-side support provides everything your printer needs to talk to the Smart Head: the `indx` temperature sensor, induction-heater control, extruder and accessory pin mapping, and the calibration commands. How you add it depends on your firmware:

- **Kalico (recommended):** support is **built in**. There is nothing to install on the host — the `[indx]` object and the `indx` sensor type are part of Kalico, and the MCU firmware ships with it too. Once you've flashed the Bondtech INDX PCB from the Kalico tree (see [Flash the Bondtech INDX PCB](#4-flash-the-bondtech-indx-pcb)), go straight to configuring your printer.
- **Klipper (mainline):** install the [`indx_klipper`](https://github.com/BondtechAB/indx_klipper) module, which adds the same host-side support to a stock Klipper install. Clone it and run its `install.sh` (see [Flash the Bondtech INDX PCB](#4-flash-the-bondtech-indx-pcb) for the commands).

The tool-change and calibration **macros** (`T0`/`T1`…, `PARK_TOOL`, the `CAL_*` helpers) are provided by the INDX macro package — see [INDX macro files](#indx-macro-files).

**Configure your printer**

After installing the plugin, add your INDX configuration to `printer.cfg`:

Add the following to your `printer.cfg`. The `serial` path under `[mcu indxmcu]` will be unique to your board; see the note below on how to find it.

```ini
[mcu indxmcu]
# Replace the serial path below with the one from your board — see "Finding your serial path" below
serial: /dev/serial/by-id/usb-Bondtech_INDX_<your-serial-here>

[indx]
mcu: indxmcu

# These are control parameters for the induction heater — leave them at these values
pid_kp: 1.0
pid_ti: 0.0
pid_td: 0.0
pid_b: 1.0

[extruder]
sensor_type: indx  # Custom sensor type provided by the INDX plugin — reads temperature via the IR sensor on the induction board
min_temp: 0
max_temp: 350

heater_pin: indx:heater
# Induction heating uses watermark (on/off bang-bang) control, not PID.
# This works well for induction because of its very fast response time. Do not change to pid.
control: watermark
nozzle_diameter: 0.4     # Change to match your passive tool nozzle size (0.4 / 0.6 / 0.8 / 1.0)
filament_diameter: 1.75

step_pin: indxmcu:motor_step
dir_pin: indxmcu:motor_dir  # If filament feeds backwards, change to: !indxmcu:motor_dir
enable_pin: !indxmcu:motor_enable
microsteps: 32
rotation_distance: 5.7  # Pre-calibrated for the DX extruder — do not change

[tmc2240 extruder]
cs_pin: indxmcu:motor_cs
spi_software_sclk_pin: indxmcu:motor_sclk
spi_software_mosi_pin: indxmcu:motor_mosi
spi_software_miso_pin: indxmcu:motor_miso
rref: 24000  # Reference resistor value for the TMC2240 on the INDX PCB — do not change
run_current: 0.6

[fan]
pin: indxmcu:part_cooling
tachometer_pin: indxmcu:part_cooling_tacho

[neopixel indx]
pin: indxmcu:led
chain_count: 16  # Fixed for the Smart Head LED array — do not change

[gcode_button endstop]
pin: ^indxmcu:endstop
press_gcode: {action_respond_info("press")}
release_gcode: {action_respond_info("release")}

[lis2dw]
# Built-in accelerometer on the INDX PCB — used for input shaper calibration
i2c_mcu: indxmcu
i2c_bus: sercom3

[angle indx]
# Magnetic encoder that reads extruder rotation — used for precise extrusion monitoring
sensor_type: as5047d
stepper: extruder
cs_pin: indxmcu:encoder_cs
spi_bus: sercom1
```

> ⚠️ **Do not change `rotation_distance`**
>
> The `rotation_distance: 5.7` value is pre-calibrated for the DX extruder and is used by the INDX tool-change macros to calculate precise filament moves during tool changes. Changing it, even slightly, will cause incorrect filament positioning and failed tool changes. Do not treat it as a value to tune. If your extrusion multiplier needs adjusting, do it in the slicer, not here.

**Finding your serial path**

The `serial` value under `[mcu indxmcu]` is unique to your board. To find it, SSH into your printer (see [Connect to your printer via SSH](#connect-to-your-printer-via-ssh)) and run:

```bash
ls /dev/serial/by-id/
```

Copy the path that starts with `usb-Bondtech_INDX` and paste it into your config.

**Configuring multiple tools**

The `[extruder]` block above is always required and represents the Smart Head's single DX extruder. INDX passive tools are **not** separate Klipper extruders — there is only ever one `[extruder]`. Additional tools (T1, T2, …) are defined in `indx.cfg`: set `variable_tool_count` and add a `variable_t{n}_x` / `variable_t{n}_dock_y` pair per tool in the `[gcode_macro TOOL_POSITIONS]` section (see [INDX macro files](#indx-macro-files)). Per-tool XY/Z offsets come from [Tool Offsets](#tool-offsets) calibration, and per-tool nozzle sizes and temperatures are set in your slicer.

##### INDX macro files

The INDX firmware plugin provides a set of `.cfg` files you include from `printer.cfg`. Each file has a specific role:

| File | Role |
| ---- | ---- |
| `indx.cfg` | User configuration: tool positions and related settings. **The only file you need to edit.** |
| `indx-tc-macros.cfg` | Tool change logic: `CHANGE_TOOL`, `PARK_TOOL`, boot detection. Do not edit. |
| `indx-cal.cfg` | Calibration macros: dock position, XY/Z offset calibration. |

Include them from your `printer.cfg`:

```ini
[include indx/indx.cfg]
[include indx/indx-tc-macros.cfg]
[include indx/indx-cal.cfg]
```

##### Required Klipper sections

The INDX macros depend on a few stock Klipper modules. If any of these are missing from your `printer.cfg`, the macros will fail at runtime rather than at startup, which makes the cause hard to spot. Add all of them:

```ini
[save_variables]
filename: ~/printer_data/config/indx_vars.cfg

[respond]
```

`save_variables` stores the state INDX has to survive a restart: the active tool, latch state, per-tool XY/Z offsets, the toolchange counter, and the current speed mode. Without it every macro that reads `printer.save_variables.variables` errors out, and the printer forgets which tool is mounted across reboots. Point `filename` at any writable path in your config directory; the file is created for you.

`respond` provides the `RESPOND` command that every INDX macro uses for console output and prompts.

##### Load cell probe

The Smart Head's load cell is the printer's Z probe, so a `[load_cell_probe]` section is required too. The ADS131M02 that reads the load cell sits on the INDX toolboard, so its pins are addressed through the `indxmcu` MCU:

```ini
[load_cell_probe]
sensor_type: ads131m02
cs_pin: indxmcu:loadcell_cs
spi_bus: sercom1
data_ready_pin: indxmcu:loadcell_drdy
channels: 0
sample_rate: 500
z_offset: -0.15
force_safety_limit: 3200
trigger_force: 150
speed: 2
retry_speed: 1.0
lift_speed: 15
pullback_distance: 0.35
pullback_speed: 0.3
samples: 3
samples_result: median
sample_retract_dist: 0.35
samples_tolerance: 0.05
samples_tolerance_retries: 3
```

The pins are named aliases rather than raw MCU pins, so this config stays valid across INDX PCB revisions.

`trigger_force` is the contact force in grams that counts as a touch.

> ⚠️ **`z_offset` is a per-machine value, not a constant.** The nozzle is the probe, so there is no probe-to-nozzle distance to correct for, but the tool and Smart Head still deflect slightly under the trigger force before contact is registered. `z_offset` takes that out. The value above came from a working machine and is a reasonable starting point; treat it as something to tune for yours rather than a number to copy. Too little and your first layer sits high, too much and the nozzle digs in.

`pullback_distance` and `pullback_speed` control what happens immediately after contact: the toolhead retracts a short distance at a slow speed while the load cell keeps sampling, and the tap analysis uses that force curve to work out the exact moment the nozzle touched. Slower and shorter gives a cleaner curve; too slow and every probe costs noticeable time.

`samples: 3` with `samples_result: median` takes three probes and keeps the middle one, which throws out a single bad reading rather than averaging it in. That matters most for `G28 Z`, where one probe decides your Z origin. `CAL_Z` runs its own convergence and median sampling across many probes on top of this (see [Z Offset Calibration](#z-offset-calibration)), so the two are not redundant; the probe-level median cleans up each individual reading that the higher-level sampling then works from.

`speed: 2` and `retry_speed: 1.0` are slow on purpose. A faster approach overshoots the trigger point before the load cell reacts, which both marks the bed and reads high.

Two values are missing from the block above on purpose: `counts_per_gram` and `reference_tare_counts`. Those come out of [load cell calibration](#load-cell-calibration) and are written to the `SAVE_CONFIG` block at the bottom of your `printer.cfg` automatically. Don't set them by hand — run the calibration and let it fill them in.

> ⚠️ **This section is Kalico-specific.** Mainline Klipper also has a `[load_cell_probe]`, but it is a different implementation and does **not** accept `pullback_distance`, `pullback_speed`, `disable_pullback_move` or `drift_safety_limit`. On mainline Klipper, drop the two pullback lines; everything else above is common to both. Note also that mainline clamps `force_safety_limit` to a minimum of 100 where Kalico allows lower values, so a config written for one is not guaranteed to load on the other.

**Running a Beacon or Cartographer as well?**

The load cell registers itself as the printer's probe, so a scanning probe on the same machine has to be told not to. For Beacon, add both of these to your `[beacon]` section:

```ini
register_as_probe: false
prefixed_probe_commands: true
```

For Cartographer, add only the first line to `[cartographer]` — it will reject `prefixed_probe_commands`.

##### Automated dock X measurement (built in)

Automated dock X measurement is **built into the INDX plugin** — there is no separate Python extra to install. The plugin registers `INDX_DOCK_MEASURE`, which energises the XY motors, homes Y then X from the dock, and derives the absolute dock position from the raw stepper counts (so it works for each tool in turn without a prior `G28`).

The `indx-cal.cfg` macros wrap this into the calibration commands you actually run:

| Command | Description |
| --- | --- |
| `CALIBRATE_DOCK_X TOOL=N` | Measures dock X for tool N via `INDX_DOCK_MEASURE` and reports the value to paste into `indx.cfg`; see [Dock Position Calibration](#dock-position-calibration) |
| `READ_DOCK_POSITION TOOL=N` | Reports the current (already-homed) X as dock X for tool N |

---

##### Homing order (important)

With a dock mounted on your printer, the default homing sequence can cause crashes. The Smart Head must move away from the dock before X is homed, and if a tool other than T0 is currently mounted it must be parked before Z is homed.

The INDX macro package includes a ready-to-use `[homing_override]` in `homing.cfg` that handles all of this. Its sequence, in full:

1. Move Z up slightly to clear the bed before any XY movement (move bed down if using a bed raiser)
2. Home Y (with reduced TMC current for sensorless homing)
3. Home X (with reduced TMC current for sensorless homing)
4. If any tool other than T0 is active: park it in the dock
5. If T0 is not already picked up: pick up T0
6. Move to bed centre and home Z

T0 is always the reference tool for Z homing. This ensures Z is always probed with the same tool, keeping Z offsets for all other tools consistent.

**Review your `PRINT_START` macro**

If you are migrating from a single-toolhead printer, your existing `PRINT_START` macro almost certainly heats the hotend before printing starts, something like `M104 S{first_layer_temperature}` or `M109 S{first_layer_temperature}`. With INDX, this will cause problems: there is no hotend to heat until a tool has been picked up by the Smart Head.

> ⚠️ Any hotend heating commands in your `PRINT_START` macro must come **after** the first tool pick-up (`T0`). Sending a heat command before a tool is picked up will result in an error, and depending on your macro structure, may cause a crash or leave the printer in a bad state.

Review your `PRINT_START` macro and move all `M104`/`M109` (and any temperature wait commands) to after the first `T0` call. If you are writing a fresh macro, pick up a tool first, then heat.

#### RRF (RepRapFirmware)

Configure the Bondtech INDX PCB in RRF following the [Duet INDX Toolboard documentation](https://docs.duet3d.com/en/Duet3D_hardware/Duet_3_family/INDX_Toolboard).

### Initial Startup

Before calibrating the dock or running any tool changes, verify that the Smart Head is communicating correctly and all connected components are working. Work through these checks in order before moving anything near the dock.

### 1. Verify MCU connection

Power on your printer and open Klipper (Mainsail or Fluidd). Check the MCU status in the interface; `indxmcu` should appear as connected.

If Klipper reports a timeout or cannot connect to `indxmcu`, the most common causes are:

- **Firmware not flashed**: the most likely cause on a first startup. If you haven't flashed the Bondtech INDX PCB yet, or the flash didn't complete successfully, go back to [Flash the Bondtech INDX PCB](#4-flash-the-bondtech-indx-pcb) before continuing
- **Incorrect `serial` path**: re-run `ls /dev/serial/by-id/` via SSH and confirm the path matches what's in `[mcu indxmcu]` in your config
- **Communication mode switch** not set correctly: confirm the switch on the INDX MCU PCB is set to CAN or USB to match your wiring. See [Switch configuration](#3-wiring) for reference images
- **INDX Link Cable** not fully seated at either end

Once `indxmcu` shows as connected, proceed.

### 2. Check extruder motor direction

With no filament loaded, issue a small extrude command from the Klipper console:

```gcode
G91           ; relative mode
G1 E10 F300   ; extrude 10mm
G90           ; back to absolute
```

> **Note:** If Klipper throws a "Cannot extrude — minimum extrude temperature" error, either heat the nozzle first (`M104 S200` and wait for it to reach temperature), or — on Kalico — allow cold extrusion at runtime with `M302 P1`. Run `M302 P0` to re-enable the protection once you've confirmed motor direction. No config change or restart is needed.

The extruder gear should turn in the direction that feeds filament through the tool. If it moves the wrong way, add `!` to the `dir_pin` in your `[extruder]` config and restart Klipper.

### 3. Check part cooling fan

If you have a part cooling fan connected to the Bondtech INDX PCB, trigger it from the console and confirm it spins:

```gcode
M106 S255   ; fan full speed
M107        ; fan off
```

Skip this step if you haven't connected a fan yet.

### 4. Verify accelerometer

The Bondtech INDX PCB has a built-in accelerometer; no external ADXL345 or similar sensor needed. Confirm it is responding:

```gcode
ACCELEROMETER_QUERY
```

You should see a stream of X/Y/Z acceleration values returned in the console. If you get an error, check the `[lis2dw]` section in your config for correct `i2c_mcu` and `i2c_bus` values.

### 4a. Run input shaper calibration (optional but recommended)

With the built-in accelerometer confirmed working, you can run Klipper's resonance testing to calibrate input shaper, with no external ADXL345 needed.

**Install the required Python dependencies**

These are not installed by default on most Klipper hosts. Run this once on your Pi:

```bash
sudo apt install python3-numpy python3-matplotlib libatlas-base-dev libopenblas-dev -y
~/klippy-env/bin/pip install numpy matplotlib --upgrade
```

Then restart Klipper:

```bash
sudo systemctl restart klipper
```

**Add the resonance tester config**

Make sure your config includes a `[resonance_tester]` section referencing the built-in accelerometer and a probe point near the centre of your bed:

```ini
[resonance_tester]
accel_chip: lis2dw
probe_points:
    <X_CENTER>, <Y_CENTER>, 20    # replace with your bed centre coordinates
```

> ⚠️ The built-in accelerometer on the INDX PCB is a **LIS2DW**, not an ADXL345. Use `accel_chip: lis2dw`, not `adxl345`.

**Run the tests**

Home the printer, then run one axis at a time from the Klipper console:

```gcode
TEST_RESONANCES AXIS=X
TEST_RESONANCES AXIS=Y
```

Klipper will move the toolhead through a frequency sweep and generate resonance data. Once both axes are done, run:

```gcode
SHAPER_CALIBRATE
```

This analyses the data and recommends input shaper settings. Apply the suggested values to your `[input_shaper]` section in your config, then save and restart Klipper.

> 💡 If `TEST_RESONANCES` returns an error about missing modules, the Python dependencies above were not installed correctly. Re-run the `apt install` and `pip install` commands and restart Klipper again.

### 5. First heat-up & heater calibration

The induction heater itself is controlled by a simple **on/off (watermark) loop**, which suits induction's very fast thermal response. Separately, the INDX board builds a **thermal model** of the nozzle and tool that it uses purely for **safety monitoring** — detecting a nozzle that isn't heating as expected, a tool pulled mid-heat, or a thermal runaway (these surface as the `ErrorTempDiff` / `ErrorHeatMax` conditions). The thermal model does not drive heating; it only supervises it. Before first use this model has to be calibrated. It is a one-time procedure per tool/cooling setup; the results are written to your config with `SAVE_CONFIG`.

> ⚠️ The nozzle gets hot during calibration. Pick up a tool first (`T0`) so a nozzle is present in the coil, and keep flammable material away from the Smart Head.

Run the commands in order from the Kalico/Klipper console:

| Command | What it does |
| --- | --- |
| `INDX_CALIBRATE` | Heats the nozzle through a controlled ramp and fits the thermal-model parameters (`max_power`, `thermal_capacity`, `to_ambient_r`) |
| `INDX_FAN_CALIBRATE` | Steps the part cooling fan through several speeds and models its cooling effect on the nozzle |
| `INDX_LOAD_FILAMENT` | Loads filament and measures its heat capacity so the model accounts for the energy the filament carries away (see below) |
| `SAVE_CONFIG` | Writes the calibrated values into your `[indx]` config section and restarts |

`INDX_CALIBRATE` and `INDX_FAN_CALIBRATE` characterise the nozzle/tool and the part cooling fan — run them once per tool type and cooling setup. Because these values feed the safety model rather than the control loop, don't hand-edit them afterwards; re-run the routine if the tool type or part cooling setup changes.

##### Calibrating a CPAP or other high-flow part cooling

CPAP blowers need more care than the dual 40×10 fans, and getting this wrong is the most common cause of a printer that runs fine until part cooling kicks in and then shuts down a minute later. That shutdown is the safety model working correctly: the fan is removing more heat than the model predicts, the divergence exceeds `max_model_error`, and the printer stops.

**Your fan must respond across the whole commanded range.** `INDX_FAN_CALIBRATE` fits a power law with a negative exponent:

```
part_cooling_fan_a × fan_speed ^ (−part_cooling_fan_k)
```

which means the fit is most sensitive at *low* fan speeds. If your fan config uses `off_below`, every commanded speed under that threshold sets the fan to zero, so the calibration records "5% commanded, no cooling measured" exactly where it matters most and the fitted curve is wrong across the entire range.

Use `min_power` rather than `off_below` for a blower. `min_power` rescales the commanded range onto the range the blower can actually turn in, so commanded speed keeps tracking real airflow all the way down:

```ini
[fan]
pin: ...
min_power: 0.14       # not off_below — set to your blower's real minimum
kick_start_time: 0.1
cycle_time: 0.0003
```

**Then calibrate in this order**, with the hose attached and the duct in its final configuration:

1. `INDX_CALIBRATE` with the part cooling fan **off**, to fit the base thermal model
2. `INDX_FAN_CALIBRATE BREAKS=50 MIN_SPEED=0.01 HOLD_TIME=20`, with the nozzle at print height (around 0.2 mm) over a clean build plate
3. `SAVE_CONFIG`

Both details in step 2 matter. Calibrating without the hose, or with the nozzle up in free air, measures airflow that doesn't match what the nozzle sees while printing — and the model is only as good as the conditions it was fitted in.

**Watch the fan through the sweep.** It should visibly change speed at every step. If it doesn't, the fan config is still truncating the low end and the fit will be wrong again no matter how many times you re-run it.

> ⚠️ **Don't raise `max_model_error` to stop the shutdowns.** A passive tool has no thermistor, so model divergence is the main thing standing between a misbehaving coil and a fire. Raising the limit hides the symptom and removes the protection. If the model keeps diverging, the fan calibration is wrong — fix that instead.

**Filament heat capacity.** Different filaments carry heat away from the nozzle at different rates, so the safety model also needs to know which filament is loaded. You set this when you load filament into a tool, not during the one-time calibration above:

- **Measure it** — `INDX_LOAD_FILAMENT` feeds and primes filament while measuring the actual heat capacity, then (with `APPLY=1`) writes it to your config. Most accurate; run `SAVE_CONFIG` to keep it.
- **Set it by type** — `INDX_SET_MODEL_PARAMS FILAMENT_DENSITY=… FILAMENT_HEAT_CAPACITY=…` applies known values for a material without measuring.

The `LOAD_FILAMENT` macro wraps both of these together with tool selection — see [Loading Filament into Tools](#loading-filament-into-tools).

**The model only uses the product.** Density and heat capacity are always multiplied together, never used separately, so how the value is split between the two doesn't matter — only that `density × heat_capacity` is right for the material. This is why a measured run reports `model_filament_density = 1.0000`: the measurement can only recover the product, so it pins density to 1 and folds everything into heat capacity. That isn't a failed measurement.

**Values are remembered per tool.** `LOAD_FILAMENT TOOL=n TYPE=…` records the filament against that tool, and every subsequent pickup of it restores those values before the tool heats. Without that, the model would keep whichever material was loaded last on any tool, which on a multi-material print is the wrong filament for most of the job. You can set it directly for a tool at any time:

```gcode
SET_TOOL_FILAMENT TOOL=1 DENSITY=1.21 HEAT_CAPACITY=1.80
```

Tools that have never been loaded through `LOAD_FILAMENT` or `SET_TOOL_FILAMENT` simply leave the model untouched on pickup.

> ⚠️ A measured run (`MEASURE=1`) applies its result globally rather than to the tool it measured, because the measurement is written by the firmware rather than the macro. After `SAVE_CONFIG` and a restart, record it against the tool with `SET_TOOL_FILAMENT TOOL=n DENSITY=1.0 HEAT_CAPACITY=<the measured value>` so it survives toolchanges.

---

**Part 3: Configuration**

---

## Configuration

### Load cell calibration

The Smart Head's load cell senses tool/nozzle touch and is the printer's **Z probe**, so it must be calibrated before the printer can home Z.

> ⚠️ **Do this before your first Z homing.** Z homing probes the bed with the load cell, so the load cell must be calibrated before a full `G28` — and therefore before dock and [Z-offset](#z-offset-calibration) calibration. It's a first-boot, by-hand step: **X and Y are homed first** (they don't use the load cell), but the tool is seated by hand because the dock can't be reached until Z is homed.

Start with **no tool on the Smart Head** and run:

```gcode
CALIBRATE_LOAD_CELL
```

This homes X and Y, opens the latch (and records soft-state Open), and tares the empty head. Now **seat a passive tool on the Smart Head by hand** — the tool **must be empty** (no filament in the extruder gears) — then calibrate against the known locking force (default 1600 g). `CALIBRATE_LOAD_CELL_APPLY` locks, samples, then unlocks again so you can remove the tool by hand.

```gcode
CALIBRATE_LOAD_CELL_APPLY GRAMS=1600
SAVE_CONFIG
```

Prefer the console? Run `LOAD_CELL_CALIBRATE`, then `TARE` with no tool, seat an **empty** tool and lock the latch, then `CALIBRATE GRAMS=1600`, `ACCEPT`, unlock the latch, and `SAVE_CONFIG`.

Restart, then home the printer (`G28`) — Z now probes with the load cell.

### Dock Position Calibration

Before any tool changes can happen, you need to find and save the exact dock position for each tool. Two coordinates are required per tool, both set in `indx.cfg`:

> 💡 **Dock calibration tool:** A printable jig ([`INDX_Dock_calibration_tool.stl`](CAD/STL/INDX_Dock_calibration_tool.stl)) is available to help align the dock during this process. Print it before starting.

| Variable | Meaning |
| --- | --- |
| `variable_t{n}_x` | X coordinate of the tool holder centre (mm) |
| `variable_t{n}_dock_y` | Y coordinate where the tool is fully seated (mm) |
| `variable_dock_dir` | Y sign into the dock: `-1` front (min Y), `+1` rear (max Y). Default `-1`. |

The trigger line (`dock_y - dock_dir * trigger_offset`) is derived automatically; you only set `dock_y`.

For a rear dock, set `variable_dock_dir: 1` and put `clearance_y` on the bed side of the tools.

> ⚠️ **Take this slow.** Moving the Smart Head into the dock area without verified coordinates is one of the most crash-prone steps in the entire INDX setup. A misaligned approach at speed can damage the Smart Head, the passive tools, or the dock itself.
>
> - **Always use the smallest jog increments available** (0.1 mm or less) when approaching a tool
> - **Never jog in Y toward the dock** until you are confident the X position is correct
> - **Keep your hand near the emergency stop** (or have it open in your browser) throughout this process
> - If anything looks wrong, stop immediately and re-evaluate before continuing

---

#### Finding dock_y (Y: fully seated position)

With the Smart Head holding the tool, carefully jog in Y in small increments until the tool is fully seated in the dock. When it feels fully engaged, run:

```gcode
CAL_SET_DOCK_Y
```

The console will report the correct `dock_y` value for that tool, calculated from your current Y position and the configured `trigger_offset`. Paste the reported value into `indx.cfg`:

```ini
variable_t0_dock_y: -26.0   # from CAL_SET_DOCK_Y output
```

Repeat for each tool and restart Klipper to apply.

---

#### Finding dock_x (X: tool centre)

Three options; choose one:

**Option A: `CALIBRATE_DOCK_X` (automated, built in)**

Measures the absolute X position without needing a prior home, using the plugin's native `INDX_DOCK_MEASURE` (which derives the dock position from the raw stepper counts across the Y+X homing sequence).

1. `M84` (disable motors)
2. Manually slide the toolhead to the T0 dock
3. Run:
   ```gcode
   CALIBRATE_DOCK_X TOOL=0
   ```
   The macro homes Y then X and reports the measured `dock_x` for that tool. Paste it into `indx.cfg`:
   ```ini
   variable_t0_x: 0.000   # from CALIBRATE_DOCK_X output
   ```
4. For each additional tool: `M84`, slide to the dock, run `CALIBRATE_DOCK_X TOOL=N`. No `FIRMWARE_RESTART` needed between tools.
5. Once all tools are recorded, `RESTART` to apply, then `G28` to restore normal machine coordinates.

**Option B: `READ_DOCK_POSITION` (if already homed)**

If the printer is already homed, jog the Smart Head to the tool's dock X position in Mainsail or Fluidd and run:

```gcode
READ_DOCK_POSITION TOOL=0
```

Reports the current X as `dock_x` for that tool. Paste the value into `indx.cfg` (`variable_t{n}_x`) and `RESTART` to apply.

**Option C: manual**

Home the printer, jog the Smart Head to the dock X for each tool, and note the X coordinate shown in the interface. Enter it as `variable_t{n}_x` in `indx.cfg`.

> 💡 **Home regularly.** Stepper motors can lose steps if a crash or hard stop occurs, meaning the position shown in your interface may no longer match the actual toolhead position. Re-home your printer (`G28`) before recording any coordinates, and again after any crash or unexpected movement. If you suspect steps have been lost, discard any coordinates taken since the last home and start that tool's calibration over.

#### First tool change test

Once you have calibrated the dock position for at least one tool, do a controlled first pick-up to confirm it works before setting up the full multi-tool configuration.

> ⚠️ **Take this slow.** Use the smallest jog increments and keep your hand near the emergency stop throughout. If anything looks wrong, stop immediately.

1. Home the printer (`G28`)
2. Pick up the tool:
   ```gcode
   T0
   ```
3. Confirm the Smart Head locks onto the tool and the nozzle begins heating
4. Once at temperature, confirm the DX extruder can feed filament (optional: extrude a short amount manually)
5. Park the tool back in the dock:
   ```gcode
   PARK_TOOL
   ```
6. Confirm the tool deposits cleanly and the Smart Head returns to a safe position

If the pick-up or deposit fails, do not retry at speed. Go back to the dock position calibration steps above and recheck the coordinates for that tool.

---

### Tool Offsets

Each passive tool has a slightly different position relative to the Smart Head pickup point. Tool offsets must be calibrated so prints align correctly when switching tools. There are several ways to do this, ranging from free manual methods to precise hardware-assisted ones.

---

### Method 1: Print and adjust (free, no extra hardware)

The simplest approach: print a multi-tool test pattern, measure any misalignment visually or with calipers, and adjust offsets in your config manually. Repeat until aligned.

This is the lowest-cost method but also the least precise and most time-consuming. It's a good starting point if you have no other hardware available. A well-regarded starting point is the [Offset XY Dual Extruder / IDEX Calibration print](https://www.printables.com/model/129617-offset-xy-dual-extruder-idex-calibration); print it with two tools, measure any X/Y misalignment with calipers, update the offsets in your config, and reprint until they align.

Because the test print uses two tools at a time, always use T0 as your reference tool and calibrate each additional tool against it separately: first print T0 + T1, then T0 + T2, then T0 + T3, and so on. Do not try to calibrate T1 against T2 directly; everything should be referenced back to T0.

**Precision:** Low–medium | **Cost:** Free

---

### Method 2: Nudge (automatic, requires small hardware)

[Nudge](https://github.com/zruncho3d/nudge) is a low-cost contact probe that automates X/Y/Z nozzle alignment. The nozzle physically touches the probe from multiple directions; software calculates exact offsets for each tool automatically.

Nudge is highly repeatable, typically below 0.003mm standard deviation over 10 samples, and can be permanently mounted inside a heated chamber. It's a popular choice in the tool changer community.

**Precision:** High | **Cost:** Low (probe hardware + printed parts)

---

### Method 3: Nozzle camera (most precise XY, higher cost)

A nozzle-mounted or fixed camera system (e.g. [Axiscope](https://github.com/nic335/Axiscope)) lets you visually align tools with sub-micron precision. Offsets are derived from image analysis rather than physical contact.

The INDX macro package includes a built-in camera calibration workflow (`CAL_01` → `CAL_02` → `CAL_03`) that automates the offset calculation once a camera is set up.

**Workflow:**

1. Pick up T0 and jog the nozzle tip to the centre of your camera crosshair. Run:
   ```gcode
   CAL_01_SET_CAMERA_REF
   ```
   This saves the current position as the reference point.

2. For each additional tool, run:
   ```gcode
   CAL_02_PREP_TOOL_CAL TOOL=1
   ```
   The macro picks up the tool and moves it to the camera position. Re-centre the nozzle in the crosshair using the jog controls, then run:
   ```gcode
   CAL_03_SAVE_XY_OFFSET
   ```
   The offset is calculated and saved automatically. Repeat for every additional tool.

Offsets are saved as `t{n}_offset_x` / `t{n}_offset_y` and applied immediately on the next tool pick-up.

**Precision:** Very high | **Cost:** Medium–high (camera hardware)

---

### Z offset calibration

Regardless of which XY method you use, Z offsets are set automatically using the load cell.

#### Z auto-calibration: CAL_Z

`CAL_Z` probes every tool with the load cell and sets all Z offsets in one automated run. T0's probe result establishes the global Z offset.

```gcode
CAL_Z
```

Prerequisites:
- Printer homed (homes automatically if not)
- **No filament available to the extruder gears in any tool** — if filament is loaded, latch engage moves during pickup can spike load-cell readings and cause calibration to fail.

Per tool, the macro:
1. Picks up the tool
2. Pre-probes 3× at a per-tool debris-clearing spot to clean the nozzle tip
3. Runs a convergence loop at a clean spot: probes repeatedly until the 4-sample rolling variance is below 0.005 mm, fuzzing to a new position if it stalls
4. Takes a median of 5 final samples as the result
5. Parks the tool

T0's median result sets the global Z reference. All other tools' offsets are saved as `t{n}_offset_z` relative to T0. Run `CAL_CHECK_OFFSETS` to inspect the results.

---

### Recommended approach

| Need | Recommended method |
| ---- | --- |
| Z offset only | `CAL_Z` |
| XY + Z, no extra hardware | Method 1 (print and adjust) or Method 2 (Nudge) for XY + `CAL_Z` for Z |
| Maximum XY precision | Method 3 (camera) for XY + `CAL_Z` for Z |

### Temperature & Induction Settings

Temperature is set in your slicer, the same way you would set it for any standard hotend: assign a target temperature to each filament or color in your project. INDX behaves like a normal hotend from the slicer's perspective.

The main difference from a traditional hotend is heat-up speed. A conventional heater block takes 30–60 seconds to reach printing temperature. With induction heating acting directly on the nozzle with very low thermal mass, INDX does it in around 4 seconds. That's what makes ~14-second tool changes possible.

**No induction-specific settings are required.** The induction board handles heating automatically. There are no power or frequency parameters to configure.

**Preheating is not supported and not possible.** Passive tools contain no electronics; there is nothing to preheat while a tool is parked in the dock. Do not configure standby or preheat temperatures for individual tools in your slicer; doing so may produce errors since the firmware has no way to act on them for a docked tool.

### Speed & Acceleration

Tool change motion speed and acceleration are controlled by three preset modes: **Stealth**, **Normal**, and **Sport**. Each mode sets a multiplier that is applied against the `max_velocity` and `max_accel` values defined in your `printer.cfg`. The macros read those limits at runtime, so the modes automatically scale to whatever printer they're running on, with no hardcoded numbers.

| Mode | G-code | Speed multiplier | Accel multiplier | XY stepper mode |
|---|---|---|---|---|
| **Stealth** | `MODE_STEALTH` | 20% | 20% | StealthChop (quiet) |
| **Normal** | `MODE_NORMAL` | 70% | 70% | SpreadCycle |
| **Sport** | `MODE_SPORT` | 100% | 100% | SpreadCycle |

**Stealth** runs the toolchange at 20% of your printer's configured limits. The XY steppers are switched to StealthChop, making the swap nearly silent. Useful for overnight printing or noise-sensitive environments. The trade-off is a longer toolchange duration and slightly higher stepper heat.

**Normal** is the default. It uses 70% of your printer's limits with SpreadCycle, a good balance of speed, noise, and reliability for most printers and materials.

**Sport** uses the full `max_velocity` and `max_accel` from your `printer.cfg`. This gives the fastest possible toolchange times for your specific printer. Make sure your configured limits are within what your printer can actually handle; if `max_velocity` or `max_accel` are set too high, Sport mode will expose that immediately. Input shaper should be tuned before running Sport; without it, high-acceleration toolchange moves can cause the steppers to lose steps.

Mode switching also sets StealthChop or SpreadCycle on every configured XY TMC driver (`tmc2208`, `tmc2209`, `tmc2130`, `tmc2240`, or `tmc5160`). On AWD setups, that includes `stepper_x1` and `stepper_y1` when present. Each driver is read from your `printer.cfg` individually, so mixed driver setups are handled correctly. If none of your XY steppers use a supported driver, the mode still changes speed and acceleration and INDX reports that the chopper mode was left untouched.

The active mode persists across reboots. To change it, run the macro from the console or add it to your start G-code:

```gcode
MODE_STEALTH   ; quiet/slow
MODE_NORMAL    ; default
MODE_SPORT     ; full speed
```

> **Note:** The speed limits are applied only during toolchange motion. As soon as the swap completes, the macros restore whatever velocity and acceleration limits the slicer set before the toolchange, and your print resumes at its normal print speeds.

---

**Part 4: Day-to-day Use**

---

## Using INDX

### Loading Filament into Tools

Filament can be loaded into a passive tool in three ways; try each and use what works best for your setup:

- **While the tool is in the dock**: convenient if the dock is easily accessible
- **While the tool is picked up by the Smart Head**: useful if the toolhead position is easier to reach
- **Before placing the tool in the dock**: load it on the bench, then dock it

There is no single correct method. Your printer geometry, spool placement, and personal preference will determine what works best.

**Guided loading with `LOAD_FILAMENT`**

The `LOAD_FILAMENT` macro handles the whole sequence for you: it picks up the tool, tells the safety thermal model which filament is loaded, heats to temperature, then feeds and primes.

```gcode
LOAD_FILAMENT TOOL=0 TYPE=PLA
```

- **`TOOL=<n>`** — which tool to load (it is picked up automatically).
- **`TYPE=<material>`** — applies a density + heat-capacity preset and a default load temperature. Built-in types: `PLA`, `PETG`, `ABS`, `ASA`, `PA`, `PC`, `TPU`. Edit the `filament_presets` table in `indx-cal.cfg` to add materials or tune values. Presets may also set an optional `speed` (mm/s) for the feed/prime step; `TPU` uses 2 mm/s so soft filament does not buckle during guided load.
- **`TEMP=<°C>`** *(optional)* — override the preset load temperature.
- **`MEASURE=1`** *(optional)* — measure this filament's actual heat capacity while loading instead of using the preset (most accurate). Run `SAVE_CONFIG` afterwards to keep it.

`LOAD_FILAMENT` needs a calibrated thermal model — run `INDX_CALIBRATE` first (see [First heat-up & heater calibration](#5-first-heat-up--heater-calibration)). The manual methods below work too; if you load by hand, set the filament's heat capacity separately so the safety model stays accurate.

**Filament path**

How filament is routed from the spool to the tool depends entirely on your printer. Common approaches include Bowden tubes from a spool holder to the dock, or direct-feeding from a nearby spool. There are no INDX-specific constraints on tube length for standard materials; route it in whatever way suits your printer.

**PTFE tube management**

With four or more tools, PTFE tube management becomes important. Loose, unrestrained tubes will move during printing and can knock into each other or into docked tools, potentially dislodging a tool from the dock mid-print, which can cause serious damage to the Smart Head, the tool, or the dock itself.

Two approaches work well:

- **Clip the tubes together**: bundle the PTFE tubes and clip them at intervals so they move as a single unit rather than independently
- **Mount the tubes rigidly along the top interior of the printer**: routing and securing the tubes along the frame keeps them stable and out of the motion path entirely. When doing this, make sure the tubes are long enough to reach all corners of the build area without pulling on the toolhead; a tube that is too short will create tension on the Smart Head as it moves, which can affect print quality or cause tool change failures

Either approach significantly reduces the risk of tubes interfering with docked tools. If you are running four or more tools, do not leave PTFE tubes unmanaged.

**Flexible filaments (TPU and similar)**

Keep the filament path as short as possible. Long Bowden paths cause flex filament to buckle rather than feed. Where possible, feed directly into the tool without a Bowden tube, or use a very short, straight tube. Avoid sharp bends in the path. `LOAD_FILAMENT TYPE=TPU` also feeds slower than other presets (2 mm/s); tune `speed` in `filament_presets` if needed.

### Performing Tool Changes

Tool changes happen automatically when triggered by your slicer's multi-material G-code. The Klipper plugin provides standard `T0`, `T1`, `T2` (etc.) macros for selecting any tool, the same commands your slicer will output.

You can also trigger a manual tool change directly from the Klipper console or a macro:

```gcode
T0  ; pick up tool 0
T1  ; pick up tool 1
T2  ; pick up tool 2
```

> ⚠️ **Never remove a tool while the nozzle is heating.** If a tool is physically removed from the Smart Head while the induction coil is active, the firmware on the Bondtech INDX PCB will crash. You will need to run `FIRMWARE_RESTART` in the Klipper console before the printer can be used again.

**Priming before a print**

It is recommended to prime each nozzle before starting a print. Priming builds pressure in the nozzle and purges any filament that has been sitting idle and may have degraded or partially retracted. How you do this is up to you; common approaches include:

- A purge line in your slicer's print start G-code
- A prime routine in your `PRINT_START` macro
- A dedicated prime tower at the start of the print

The specifics depend on your slicer and macro setup. Check what other tool changer users in the community are doing for inspiration.

### Slicer Setup

Any slicer that supports **multiple filaments or colors** works with INDX; slicer compatibility is not INDX-specific. If your slicer can output multi-tool G-code (`T0`, `T1`, `T2`…), INDX can execute it.

Common slicers used with INDX include PrusaSlicer, OrcaSlicer, SuperSlicer, and Cura. Refer to your slicer's documentation for how to configure multiple extruders/tools.

**INDX-specific slicer settings to be aware of:**

- **Wipe tower:** A wipe tower is recommended for best results but not strictly required. Because INDX produces near-zero ooze by design, the wipe tower can be kept small compared to filament-switcher systems. You can experiment with disabling it for single-material-per-layer prints, but use it when printing materials prone to stringing.
- **Tool change G-code:** A small custom G-code snippet is required in your slicer's tool change script. The snippet and where to add it differs per slicer:

  **OrcaSlicer**

  Add under Printer Settings → Machine G-code → Change filament G-code:
  ```gcode
  CHANGE_TOOL TOOL={next_extruder} TEMP={nozzle_temperature[next_extruder]}
  M400
  ```

  `TEMP=` tells the toolchange what the incoming tool should heat to. Without it the macro can only fall back to the outgoing tool's temperature, which is correct when both tools print at the same temperature and wrong when they don't: the new tool gets brought to the old filament's temperature and only corrected afterwards. Passing it heats each tool to its own temperature once, with no overshoot and no second wait.

  **PrusaSlicer / SuperSlicer**

  1. Under Printer Settings → General → Capabilities, set **Number of extruders** to match your tool count
  2. Make sure **Single Extruder Multimaterial Printer** is **unchecked**; this mode is for filament switchers (MMU/AMS) and must be off for a tool changer
  3. Under Printer Settings → Custom G-code → Tool change G-code, add:
  ```gcode
  T{next_extruder}
  {if (wipe_tower)}
  G0 Y{wipe_tower_y+2} X{wipe_tower_x+2} F{travel_speed*60}
  G0 Z{layer_z} F{travel_speed*60}
  {endif}
  M104 S{temperature[next_extruder]}
  TEMPERATURE_WAIT SENSOR=extruder MINIMUM={temperature[next_extruder]-5} MAXIMUM={temperature[next_extruder]+5}
  ```

  This selects the next tool, moves to the wipe tower (if one is enabled) so the new (initially cold) tool heats and purges there, then sets the new tool's temperature and waits for the induction coil to bring it up to temperature before printing resumes.

  This snippet works as written and needs no changes. If your tools print at different temperatures you can optionally replace the `T{next_extruder}` line with the form below, which heats the new tool straight to its own temperature instead of reaching the old tool's first and correcting afterwards:

  ```gcode
  CHANGE_TOOL TOOL={next_extruder} TEMP={temperature[next_extruder]}
  ```

  Keep the `M104` and `TEMPERATURE_WAIT` lines either way; they cost nothing once the temperature is already correct.

  **SuperSlicer** uses the same template engine and variable names as PrusaSlicer, so this snippet works unchanged in both. (PrusaSlicer's older `[...]` placeholder form also works in both if you prefer it, e.g. `M104 S[temperature[next_extruder]]`.)

  **Cura**

  > ⚠️ This configuration has not been fully verified. If you run into issues, ask on the [Bondtech Discord](https://discord.gg/XDX9jDXN6e).

  Cura handles tool changes differently from the PrusaSlicer family: it emits the `T{n}` command automatically and runs **per-extruder** start/end G-code, so there is no single "tool change G-code" field to edit. Configure it as follows:

  1. In **Settings → Printer → Manage Printers → Machine Settings**, set **Number of Extruders** to match your tool count. Cura then outputs `T0`, `T1`, … automatically at each tool change.
  2. Enable **Prime Tower** (search "prime tower" in the print settings). This is Cura's equivalent of the wipe tower; Cura moves to it and purges the freshly heated tool automatically, so you don't script the move yourself.
  3. In **Machine Settings**, open each extruder's tab and add to its **Extruder Start G-code** (this runs every time that tool becomes active):
  ```gcode
  M104 S{material_print_temperature}
  TEMPERATURE_WAIT SENSOR=extruder MINIMUM={material_print_temperature}
  ```

  > **Notes for Cura:**
  > - Cura's start/end G-code does **not** support arithmetic in placeholders (e.g. `{material_print_temperature - 5}` will not work), so use the bare target. Because an INDX tool is always cold when picked up, waiting on `MINIMUM` alone is sufficient; the nozzle only ever needs to heat *up* to temperature.
  > - Do **not** set per-extruder **Standby Temperature** values; passive tools cannot be preheated in the dock (see [Temperature & Induction Settings](#temperature--induction-settings)).
- **Slicer profiles:** Pre-made printer profiles for INDX are being developed and will be made available before release. They are not ready for general use yet.

---

**Part 5: Designing for INDX**

---

## Designing for INDX

This section is for users who want to design custom mounts, docks, or printer integrations for INDX.

### Dock Design

The dock holds passive tools in precise, repeatable positions so the Smart Head can pick them up reliably. There are strict geometry requirements; a dock that doesn't meet them will cause failed or inconsistent tool changes.

The reference dock design is available on [github.com/BondtechAB/INDX](https://github.com/BondtechAB/INDX). Use it as the starting point for any custom design.

**Key design constraints**

Each dock is approximately **70mm tall, 28.5mm wide (X), and 25mm deep (Y)**. Minimum tool center-to-center spacing is **34mm** bare, or **41mm** when using the Bondtech part cooling solutions. The design must achieve a pickup repeatability of **within 0.2mm**.

**Material recommendations**

Bondtech's sold docks use SLS-printed Nylon 12 GF. For self-printed docks, use a material that is dimensionally stable at elevated temperatures; the dock sits near the print area and will experience heat cycles. ASA or ABS are common choices. Avoid PLA.

**Community designs**

Community dock designs for specific printers and frames will be collected on [github.com/BondtechAB/INDX](https://github.com/BondtechAB/INDX). If you design a dock for an unlisted setup, submit it via pull request.

### Part Cooling

INDX's modular part cooling system is designed to be extended by the community. The cooling solution snaps onto the outside of the Smart Head cowlings; the interface geometry is defined in the cowling CAD files, which Bondtech will publish on [github.com/BondtechAB/INDX](https://github.com/BondtechAB/INDX).

If you design a custom part cooling solution using the cowling CAD files as a reference, we'd love to see it. Community-contributed cooling designs will be collected in the GitHub repository. Submit yours via pull request.

### CAD Files & Templates

All official CAD files are hosted on **Bondtech's GitHub**: [github.com/BondtechAB/INDX](https://github.com/BondtechAB/INDX)

**Reference geometry (STEP)**

The STEP file is the master reference model; it contains the geometry of every printable part listed below, so use it as the starting point for designing custom mounts, adapters, or cooling solutions.

| File | Format | Description |
| ---- | --- | --- |
| [`INDX_simplified_1.17.step`](CAD/INDX_simplified_1.17.step) | STEP | Simplified reference model of the full INDX assembly, includes all printable parts below |

**Printable parts (STL)**

These are print-ready STLs of the individual parts. They are all derived from the reference STEP above.

| File | Part | Description |
| ---- | ---- | --- |
| [`INDX_MGN12H_X-carriage.stl`](CAD/STL/INDX_MGN12H_X-carriage.stl) | X-carriage adapter | Mounts the Smart Head to MGN12H linear rails (6mm belts) |
| [`INDX_Front_cover_left.stl`](CAD/STL/INDX_Front_cover_left.stl) | Smart Head cover | Front cover, left half |
| [`INDX_Front_cover_right.stl`](CAD/STL/INDX_Front_cover_right.stl) | Smart Head cover | Front cover, right half |
| [`INDX_PCB_Cover.stl`](CAD/STL/INDX_PCB_Cover.stl) | PCB cover | Protective cover for the Bondtech INDX PCB |
| [`INDX_Part_Cooling_Interface_left.stl`](CAD/STL/INDX_Part_Cooling_Interface_left.stl) | Part cooling mount | Fan shroud clip, left. Attaches a fan shroud to the left Front Cover; see [Install the Smart Head](#1-install-the-smart-head) |
| [`INDX_Part_Cooling_Interface_right.stl`](CAD/STL/INDX_Part_Cooling_Interface_right.stl) | Part cooling mount | Fan shroud clip, right. Attaches a fan shroud to the right Front Cover |
| [`INDX_4010_Duct_Left.stl`](CAD/STL/INDX_4010_Duct_Left.stl) | Part cooling (4010) | Dual 40×10 blower duct, left half |
| [`INDX_4010_Duct_Right.stl`](CAD/STL/INDX_4010_Duct_Right.stl) | Part cooling (4010) | Dual 40×10 blower duct, right half |
| [`INDX_CPAP_Duct_Left.stl`](CAD/STL/INDX_CPAP_Duct_Left.stl) | Part cooling (CPAP) | CPAP duct, left half |
| [`INDX_CPAP_Duct_Right.stl`](CAD/STL/INDX_CPAP_Duct_Right.stl) | Part cooling (CPAP) | CPAP duct, right half |
| [`INDX_CPAP_Duct_Top.stl`](CAD/STL/INDX_CPAP_Duct_Top.stl) | Part cooling (CPAP) | CPAP duct, top manifold |
| [`INDX_Beacon_Cartographer_Mount.stl`](CAD/STL/INDX_Beacon_Cartographer_Mount.stl) | Probe mount | Mount for a Beacon / Cartographer scanning probe |
| [`INDX_Dock_calibration_tool.stl`](CAD/STL/INDX_Dock_calibration_tool.stl) | Dock calibration tool | Printed jig for calibrating dock position during initial setup; see [Dock Position Calibration](#dock-position-calibration) |

The repository is licensed under **GPL-3.0**.

More files (dock templates, additional X-carriage adapters, tool body templates) will be added as the project develops. Community contributions are welcome via pull request.

---

**Part 6: Maintenance, Support & Community**

---

## Maintenance

The Smart Head's mechanism is designed to run for a long time with minimal upkeep, but a periodic inspection keeps tool changes reliable and prevents wear from going unnoticed.

**How often:** Perform this inspection every **500,000 tool cycles**. More frequent checks can be beneficial. If you don't change tools often, inspect roughly every **1,000 print hours** instead.

Work through the following checks:

- **Check for play in the opening mechanism and drive gear assembly.** There should be no slop anywhere. Feel the nozzle lever assembly pin to confirm there is no play in the opening mechanism or in the drive gear assembly.
- **Check the activator moves freely.** With the extruder fully closed, the activator should be able to be pushed slightly up and down easily, without sticking or catching.
- **Check the magnet activator assembly.** It should move completely friction-free, with no resistance.
- **Inspect the coil for nozzle contact.** Check that misaligned (crooked) nozzles have not struck the coil. The coil area should be free of any marks left by a nozzle.
- **Inspect the gears.** Check that the drive gear assembly is not damaged and that the gears are not worn.
- **Grease the gear teeth.** Apply fresh grease to the drive gear teeth and the motor gear teeth.

### Nozzle clog: cold pull procedure

A cold pull clears carbonized plastic, debris, and partial or full clogs from the nozzle. It is the most effective way to restore a blocked or under-performing tool.

**What you need:** Standard PLA filament. Use a light color so you can inspect the extracted debris.

**Steps:**

1. **Park the tool and disconnect the PTFE tube.** Park the target tool. With the Smart Head receiver open, remove the tool from the dock and disconnect the PTFE tube from the top of the tool. Check that no loose filament or debris remains in the upper guide channel.

2. **Seat the tool in the Smart Head.** Manually insert the tool into the Smart Head, keeping the receiver open throughout the entire procedure.

3. **High-temperature flush.** Set the nozzle temperature to **250–280°C**. Once at temperature, feed PLA manually down into the tool and push until ~30mm extrudes from the nozzle tip. This fills the melt zone and integrates any old residue into the new PLA plug.

4. **Cool and pack.** Drop the temperature setpoint to **120°C**. While the tool cools, maintain steady downward pressure on the filament. This counteracts shrinkage and ensures the PLA packs tightly into the nozzle geometry.

5. **Pull.** When the temperature reaches 120°C, press the tool body firmly down into the Smart Head with one hand to hold it in place. With the other hand, pull the filament slowly and steadily upward. Increase force gradually until the plug releases from the nozzle walls and slides out. Pulling too fast will snap the filament before the plug clears.

6. **Smooth withdrawal.** Once the plug releases, maintain a steady, continuous upward motion until the entire PLA strand is fully extracted from the tool.

**Verify the result.** Inspect the tip of the extracted plug. On a CHT tool, a successful pull shows **three separate thin strands** at the tip — the negative impression of the CHT internal geometry. A blunt or broken tip means the plug didn't release cleanly; repeat the cycle.

Repeat the full cycle **2–3 times** to ensure all carbonized material and debris are fully extracted.

---

## Troubleshooting

### Tool not picking up reliably

If the Smart Head consistently fails to pick up a tool, or picks up unreliably, work through these causes in order:

**Dock position miscalibrated**

This is the most common cause. Even a small X or Y offset is enough to cause failed or inconsistent pickups. Go back to [Dock Position Calibration](#dock-position-calibration) and redo the alignment for the affected tool. Re-home the printer first (`G28`) to make sure the coordinates are accurate before recording anything.

**Lost steps from a previous crash**

If the Smart Head has crashed into the dock or a tool, the stepper motors may have lost steps. This means the position shown in your interface no longer matches the actual toolhead position; coordinates you saved before the crash may now be wrong. Re-home the printer and redo dock position calibration for any tools affected.

**Dock not mounted rigidly**

If the dock has shifted or flexes during operation, the tool positions will no longer match the calibrated coordinates. Check that the dock is firmly secured to its mounting point; no movement should be possible when you push on it. Retighten any fasteners and redo dock position calibration after.

### Nozzle not reaching temperature / overheating

The induction coil is fast and powerful; it can heat the nozzle to dangerously high temperatures quickly. If you are seeing the nozzle under-read (temperature reported lower than actual) or unexpectedly overheating, the most likely cause is that the passive tool is not fully seated or is misaligned in the Smart Head.

When the nozzle is not correctly positioned inside the coil, the IR sensor reads the temperature from a suboptimal angle, resulting in a lower reading than the actual nozzle temperature. The firmware then continues heating to compensate, causing the nozzle to overheat beyond the intended target.

> ⚠️ Do not allow paper, wiring, or other flammable material near the induction coil area. Keep firmware up to date; incorrect firmware versions may not correctly limit heating.

**If the nozzle is not reaching temperature:**
- Verify the passive tool is fully picked up and seated correctly in the Smart Head; it should click into the Maxwell coupling and show no visible misalignment
- Check that the tool has not been bent or damaged in a way that affects its position inside the coil
- Confirm the firmware is up to date

**If the nozzle is overheating:**
- Immediately cancel any print or heating command
- Inspect the tool for misalignment or damage
- Do not continue using the tool until the cause is identified

### Filament jam in passive tool

Filament jams in a passive tool are resolved the same way as any standard FDM nozzle jam:

1. Heat the nozzle to printing temperature for the material that is stuck
2. Attempt a manual retraction to pull the filament back out; if it doesn't move, heat slightly higher and try again
3. If the filament has broken inside the tool, carefully remove the tool from the dock and clear the jam from the top of the filament path using a thin wire or fresh filament to push the remnant out
4. Inspect the PTFE tube inside the tool for damage or deformation; replace it if it has been heat-damaged
5. Check the nozzle for a partial or full clog and clean or replace as needed

For persistent clogs or partial blockages that survive the steps above, use the [cold pull procedure](#nozzle-clog-cold-pull-procedure).

### DX extruder not opening or closing correctly after a crash

If the Smart Head has crashed into the dock, a tool, or part of the printer frame, the DX extruder mechanism may have been physically damaged. Symptoms include:

- The extruder no longer grips filament properly
- The extruder arm does not open or close as expected when a tool is picked up or deposited
- Inconsistent extrusion or grinding sounds during extrusion

**What to do**

Visually inspect the Smart Head for any obvious physical damage: bent parts, broken clips, or anything that looks out of position. Do not attempt to force the mechanism open or closed if it is stuck.

If hardware damage is confirmed or suspected, contact Bondtech support at [bondtech.se/contact](https://www.bondtech.se/contact/) before continuing to use the system. Running with a damaged DX extruder can cause print failures and may cause further damage.

### `indxmcu` not connecting

If Klipper reports a timeout or cannot find `indxmcu` on startup, work through these causes:

- **Firmware not flashed**: the most likely cause on a first startup. If you haven't flashed the Bondtech INDX PCB, or the flash didn't complete successfully, the board will not appear. Go back to [Flash the Bondtech INDX PCB](#4-flash-the-bondtech-indx-pcb) and redo the process.
- **Wrong `serial` path**: the path in `[mcu indxmcu]` must match exactly. SSH into your printer and run `ls /dev/serial/by-id/` to get the correct path, then update your config and restart Klipper.
- **Communication mode switch not set correctly**: check the switch on the INDX MCU PCB matches your communication mode (CAN or USB). See [Wiring](#3-wiring) for reference images.
- **INDX Link Cable not fully seated**: check both ends of the cable at the Link Board and the Bondtech INDX PCB.

**Recovery: CAN_RESET jumper**

If the board has non-functioning firmware and cannot be reached normally, you can force a firmware re-fetch using the CAN_RESET jumper on the Bondtech INDX PCB:

1. Power down the printer
2. Install the CAN_RESET jumper on the PCB
3. Power up; the bootloader will reset the CAN address to the default (121) and fetch and install new firmware, even if firmware is already present
4. Once flashing is complete, power down, remove the CAN_RESET jumper, and power up again

### Link Board not detected on Raspberry Pi 3

If you are running a **Raspberry Pi 3** and the Link Board is not being detected as a USB device, even though the cable is connected and the board is powered, you may be hitting a known kernel bug affecting USB device enumeration on the Pi 3.

**Symptom:** `ls /dev/serial/by-id/` returns nothing, or the Link Board disappears after a reboot, despite the board being powered.

**Fix:**

1. SSH into your Raspberry Pi and open the boot config file:

   ```bash
   sudo nano /boot/firmware/config.txt
   ```

2. Use the arrow keys to scroll to the very end of the file. Add the following on its own line (make sure the entire entry is on a single line with no line breaks):

   ```
   dtoverlay=dwc2
   ```

3. Save the file: press **Ctrl+O**, then press **Enter** to confirm.

4. Exit nano: press **Ctrl+X**.

5. Verify the line was added correctly before rebooting:

   ```bash
   grep "dtoverlay=dwc2" /boot/firmware/config.txt
   ```

   You should see `dtoverlay=dwc2` printed back. If nothing is returned, open the file again and repeat from step 2.

6. Reboot your Raspberry Pi:

   ```bash
   sudo reboot
   ```

After rebooting, run `ls /dev/serial/by-id/` to confirm the Link Board is now visible, then continue with Klipper configuration.

> See the upstream kernel issue for background: [raspberrypi/linux#6100](https://github.com/raspberrypi/linux/issues/6100)

### Smart Head crashes into dock on homing

If the Smart Head slams into the dock or the docked tools when you run `G28`, the most likely cause is that the homing order has not been configured. By default, Klipper homes X before Y; if the Smart Head is near the dock when homing starts, a full-speed X move can send it directly into the dock.

Add a `[homing_override]` section to your `printer.cfg` that homes Y before X. See [Homing order](#homing-order-important) for the recommended config. After any crash, re-home the printer before moving on; the stepper motors may have lost steps, making the position shown in your interface unreliable.

### Extruder feeding filament in the wrong direction

If filament moves backward (out of the nozzle) when you issue an extrude command, the motor direction is inverted. Add `!` to the `dir_pin` line in your `[extruder]` config and restart Klipper:

```ini
dir_pin: !indxmcu:motor_dir
```

Re-run the extrude check from [Initial Startup](#2-check-extruder-motor-direction) to confirm the direction is now correct.

### "Cannot extrude — minimum extrude temperature" error

Klipper prevents extrusion below a minimum temperature to protect against cold extrusion. This commonly appears during initial startup when you try to verify motor direction before the nozzle is hot.

Either heat the nozzle to printing temperature first (`M104 S200` and wait), or — on Kalico — allow cold extrusion at runtime with `M302 P1` (no config change or restart needed). Run `M302 P0` to re-enable the protection once you've confirmed motor direction.

> **Note:** Tool changes themselves are not affected by this — the latch moves during a tool change run through `INDX_EXTRUDER_MOVE`, which operates the extruder cold without touching `min_extrude_temp`. This only comes up for manual extrude/direction checks.

### Heatsink fan runs continuously on startup

The heatsink fan defaults to running continuously when the Bondtech INDX PCB has no firmware installed, or while firmware is being updated. If the fan runs non-stop and the printer cannot connect to `indxmcu`, flash the firmware; see [Flash the Bondtech INDX PCB](#4-flash-the-bondtech-indx-pcb).

### Accelerometer not responding

If `ACCELEROMETER_QUERY` returns an error, check that the `[lis2dw]` section in your config has the correct `i2c_mcu` and `i2c_bus` values:

```ini
[lis2dw]
i2c_mcu: indxmcu
i2c_bus: sercom3
```

If the values are correct and the accelerometer still doesn't respond, check that `indxmcu` itself is connected; an MCU connection issue will prevent all sensor reads.

### PTFE tube knocks a tool out of the dock mid-print

If a docked tool is being displaced during a print, loose PTFE tubes are the most likely cause. With four or more tools, unrestrained tubes move freely during toolhead motion and can knock into docked tools hard enough to dislodge them.

Bundle and clip the PTFE tubes together so they move as one unit, or route and secure them along the top interior of the printer frame. If a tool has been knocked out of the dock, cancel the print, re-seat the tool, and add tube management before continuing.

### Slicer not triggering correct tool changes

If tools are not being swapped during a print, or the slicer is generating incorrect tool change G-code, check the following:

**PrusaSlicer / SuperSlicer:** Make sure **Single Extruder Multimaterial Printer** is **unchecked** under Printer Settings → General → Capabilities. This mode is for filament switchers (MMU, AMS) and generates the wrong G-code for a tool changer. With it enabled, the slicer will not output standard `T0`, `T1`… commands.

**All slicers:** Confirm you have added the required tool change G-code snippet for your slicer. Without it, the slicer may pause or error at tool changes rather than triggering the INDX macros. See [Slicer Setup](#slicer-setup) for the correct snippet for your slicer.

---

## FAQ

**How many tools can I run simultaneously?**

For the Development Kit, there is no fixed limit; you can run as many tools as your printer has physical space for in the dock. The Prusa CORE One / CORE One L kit supports up to 8 tools, as that is the maximum that fits in the Prusa enclosure.

**Does each tool need its own filament spool?**

Yes. Each passive tool has its own direct filament feed. There is no shared filament path.

**Do I need a wipe tower?**

A wipe tower is recommended but not required. INDX produces near-zero ooze by design, so the wipe tower can be kept much smaller than with filament-switcher systems. Whether you need one depends on the materials you're printing with.

**Will it work with my [printer model]?**

If your printer is CoreXY with open firmware, it's likely compatible. Community-contributed configs and integration guides live on [github.com/BondtechAB/INDX](https://github.com/BondtechAB/INDX). If your printer isn't listed, you can contribute an integration.

**Can I mix nozzle sizes?**

Hardware-wise, yes. There is no restriction on mixing nozzle sizes across tools. Each Thin Passive Tool carries its own nozzle independently, so a setup with e.g. two 0.4mm, one 0.6mm, and one 0.8mm tool is fully valid. Whether your slicer supports assigning different nozzle diameters per extruder is a slicer question, not an INDX limitation.

Note that the **Prusa CORE One / CORE One L kit** ships with either 4 or 8 tools, all 0.4mm CHT; this is fixed and cannot be customized at order time. You can however add extra tools in other sizes to your order separately.

**What happens if a tool change fails mid-print?**

If a tool change fails, the printer errors out with a thermal error and the print is not recoverable.

**Is the induction heating safe? Any RF interference concerns?**

Yes. INDX has been tested and approved in accordance with Swedish law and the guidelines set by **Elsäkerhetsverket** (the Swedish National Electrical Safety Board), which is the authority responsible for electrical safety and electromagnetic compatibility (EMC) in Sweden. Elsäkerhetsverket enforces the EU Low Voltage Directive (LVD, 2014/35/EU) and the EMC Directive (2014/30/EU), which together require that electrical products are safe to use and neither cause nor are susceptible to electromagnetic interference.

The induction coil in the Smart Head operates at close range and low power, producing a highly localized magnetic field at the nozzle. It is not a transmitter in any meaningful sense; it does not emit RF energy across the room. EMC testing confirmed no interference with 3D printers, Wi-Fi networks, or other common equipment in the same space.

**Can I add more tools after initial setup?**

Yes. Additional Thin Passive Tools can be purchased and added at any time, from both Bondtech and Prusa.

For the **Development Kit**, the limit is physical dock space. There is no firmware cap; run as many tools as your printer can fit.

For the **Prusa CORE One / CORE One L kit**, both printers are physically limited to 8 tools maximum. You can purchase additional tools beyond what came in your kit, but you cannot exceed 8 installed tools on the printer.

**Does INDX work with Marlin?**

No. INDX requires Klipper, Kalico, or RepRap Firmware (RRF). Marlin is not supported.

**Can I set standby or preheat temperatures for parked tools?**

No. Passive tools contain no electronics; there is no way to heat a tool while it is sitting in the dock. Do not configure standby temperatures for individual tools in your slicer; the firmware has no way to act on them and it will produce errors.

**Is RRF (RepRapFirmware) supported?**

Yes. See the [Duet INDX Toolboard documentation](https://docs.duet3d.com/en/Duet3D_hardware/Duet_3_family/INDX_Toolboard) for RRF flashing and configuration, plus the [Firmware Configuration: RRF](#rrf-reprapfirmware) section. Ask on the [Bondtech Discord](https://discord.gg/XDX9jDXN6e) if you need help.

---

## Community & Contributing

The INDX ecosystem is built by the people running it. Bondtech maintains the core hardware and firmware, but the printer integrations, dock designs, part cooling solutions, and real-world usage guides come from community members who've done the work and shared it. If you've got INDX running, you're in a position to save the next person significant time.

- **Chat & community help:** [Bondtech Discord](https://discord.gg/XDX9jDXN6e), the best place for quick questions, sharing builds, and getting community support
- **Official support:** For issues with your hardware or order, submit a ticket at [bondtech.se/contact](https://www.bondtech.se/contact/)
- **CAD files & community configs:** [github.com/BondtechAB/INDX](https://github.com/BondtechAB/INDX)
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

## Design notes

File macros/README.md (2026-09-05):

# DEMON INDX MACROS

These differ from the stock Bondtech ones a little here & there but essentially they're mostly the same in their function.

Most changes are to help facilitate the dock sensors. All macro files found here need to be installed & used together. If you don't have any dock sensors thats ok as they are dormant by default in the modified index.cfg file.

These macros also require [KAMP_LiTE](https://github.com/3DPrintDemon/KAMP_LiTE/releases/tag/v1.0)

<br>

# DEMON DISCORD!

Come & join the community! We've launched Demon Discord, help us start building a fantastic user focused resource for help & support from other users, or simply chat & show off your machine & your latest prints!

<p align="left">
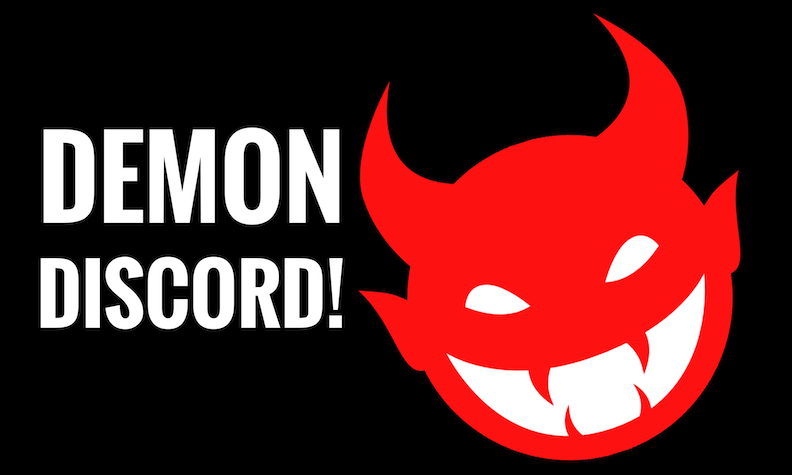
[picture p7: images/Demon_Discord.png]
Demon_Discord
    
    <https://discord.gg/KEbxw22AD4>
</p>

[https://discord.gg/KEbxw22AD4](https://discord.gg/KEbxw22AD4)

<br>

# DESIGNED FOR USE WITH INDX DEMON DOCKS!

>[!NOTE]
> These macros can be used without dock sensors just as normal! You will need at minimum the indx.cfg & indx-tc-macros.cfg files for standard operation. The rest are required if you do have dock sensors.

Add dock sensing to your INDX system! Use this modified standard INDX dock so installs & dock placement DO NOT change! You just need a MCU to manage the docks & a cable run from the docks to said MCU.

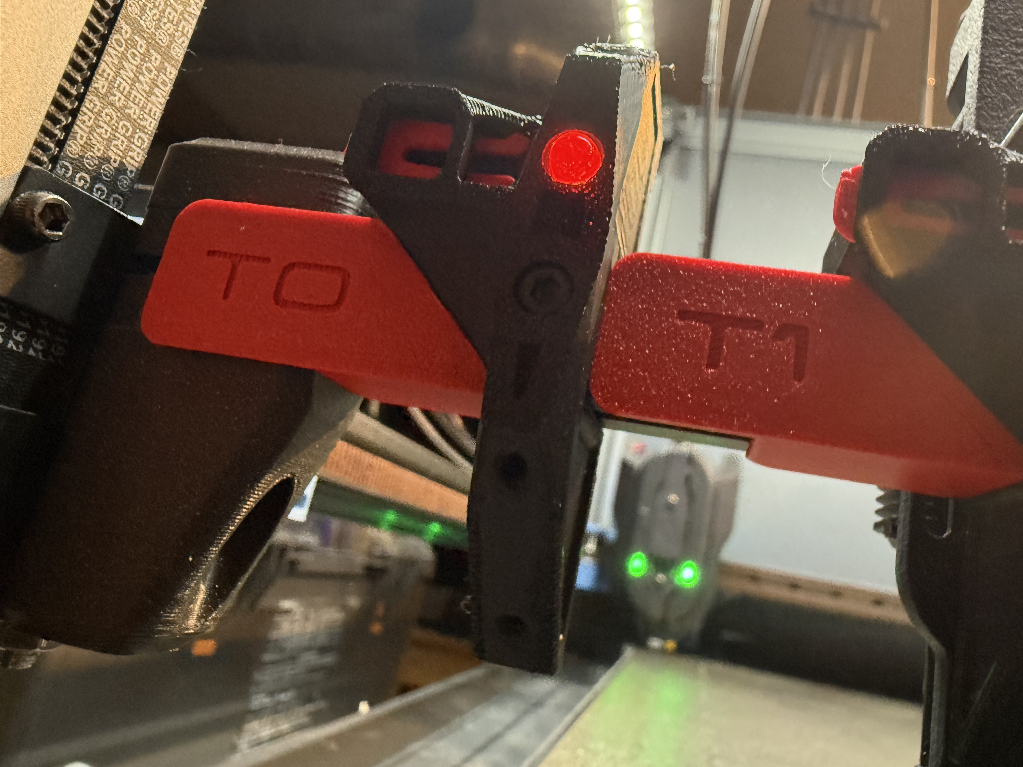
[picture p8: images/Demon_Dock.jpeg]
Demon_Dock


This system allows active tool sensing with load cell confirmation for all attached docks with simple & accurate switch connection to a non-critical MCU. 

DEMON_DOCKS will auto scan for empty docks at startup & disable sensing for those docks. They can be added back into active docks (or removed again) at runtime by command/macro button. The docks can be set to warn only of a potential problem, raise errors if not printing, PAUSE the print if printing, emergency stop if not printing, or emergency stop when printing. 

The load cell dock/undock confirmation can be set on/off at runtime.

The system warns of:

- Undocked tools at startup that will be ignored
- ignored docks during tool changes
- inactive tools undocked at any time
- problems during non-printing operations
- load cell readings out of range
- docking failures - printing & non-printing
- pickup (undocking) failures - printing & non-printing

DEMON_DOCKS then takes specified actions for each type of occurrence.

It can even pause a tool change while printing if a problem is detected!

<br>

### Download [DEMON DOCKS here!](https://github.com/3DPrintDemon/DEMON_INDX/tree/main/DEMON%20Docks)

<br>

# Important Slicer Setting

For these macros to work effectively you need to go to your Printer Settings / Multilateral tab & check "Tool change on wipe tower"

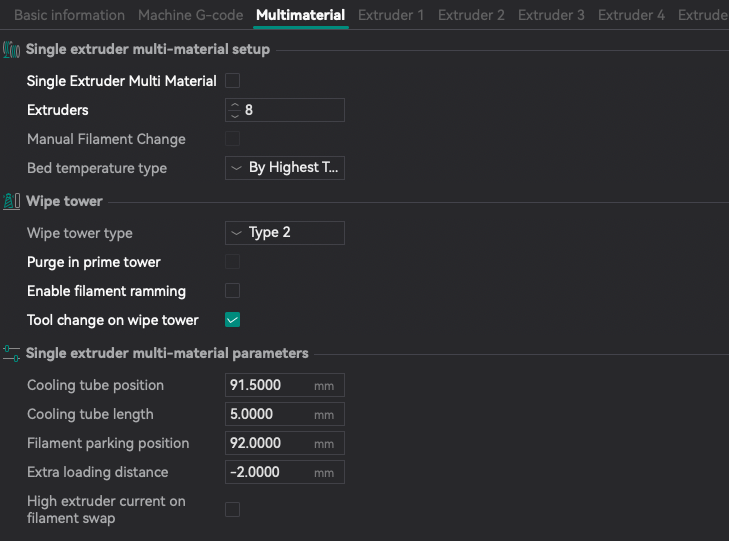
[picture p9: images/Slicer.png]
Slicer


# Slicer Machine G-code For DEMON_INDX_EXTRAS.cfg

These are the sections to add to ORCA slicer:

Machine Start G-code:
```
SET_PRINT_STATS_INFO TOTAL_LAYER=[total_layer_count]
M104 S0  ; Stops the slicer from sending temp waits separately
M140 S0
_TOOL_CHECK_START
PRINT_START EXTRUDER=[nozzle_temperature_initial_layer] TOOL={initial_tool} BED=[bed_temperature_initial_layer_single]
```

Machine End G-code:
```
PRINT_END
```

Before Layer Change G-code:
```
;[layer_z]
G92 E0
```

After Layer Change G-code:
```
;[layer_z]
SET_PRINT_STATS_INFO CURRENT_LAYER={layer_num + 1}
M117 Layer {layer_num+1}/[total_layer_count] : {filament_settings_id[0]}
```

Filament Change G-code:
```
CHANGE_TOOL TOOL={next_extruder} TEMP={nozzle_temperature[next_extruder]}
M400
```

Pause G-code:
```
PAUSE
```

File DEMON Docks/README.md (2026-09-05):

Demon_Dock

# INDX DEMON DOCKS!

Add dock sensing to your INDX system! Use this modified standard INDX dock so installs & dock placement DO NOT change! You just need a MCU to manage the docks & a cable run from the docks to said MCU.

<br>

NOTE: Requires [DEMON_INDX](https://github.com/3DPrintDemon/DEMON_INDX/tree/main/macros) macros

<br>

This system allows active tool sensing with load cell confirmation for all attached docks with simple & accurate switch connection to a non-critical MCU. 

DEMON_DOCKS will auto scan for empty docks at startup & disable sensing for those docks. They can be added back into active docks (or removed again) at runtime by command/macro button. The docks can be set to warn only of a potential problem, raise errors if not printing, PAUSE the print if printing, emergency stop if not printing, or emergency stop when printing. 

The load cell dock/undock confirmation can be set on/off at runtime.

The system warns of:

- Undocked tools at startup that will be ignored
- ignored docks during tool changes
- inactive tools undocked at any time
- problems during non-printing operations
- load cell readings out of range
- docking failures - printing & non-printing
- pickup (undocking) failures - printing & non-printing

DEMON_DOCKS then takes specified actions for each type of occurrence.

It can even pause a tool change while printing if a problem is detected!
 
# BOM

- x1 (or more) MCU(s) capable of handling the amount of tools & dock sensors you have.
  I chose a BTT MMB (v1.0) as that's what I had, a v1.1 would be better choice. A v2.0 would also work but would appear to have reduced ready to go pins for this. Should still be fine.
  All units also provide great scope for expansion! See the BTT Github for full capabilities.

- approximately 2m of 30-32 AWG x3 colours for each tool on a 350 sized Voron 2.4 style printer
  (So 6m of wire total for each tool over 3 colours. V+ = RED, V- = BLACK, Signal = OTHER)

- x1 D2F-5L switch per tool

- x1 5v 5mm LED (with resistor) per tool - colour of your choice
  The can be bought from most good stockists including Amazon

- x2 S-03-08-N magnets per tool dock (3mmx8mm)

- 1-1.5m Nylon expandable cable sleeve 10mm(ish) for your wires

- No extra bolts or other special hardware needed outside of the requirements of standard Bondtech docks
  You will still need the spring, S-05-08-N magnet, 1515 retaining bolt & nut, also printed Magnet holder slider & dock clip.

# Printing

- Print FMD ASA or PC or better (SLS)

- No supports are required - TURN THEM OFF NOW!

- Set layer height to 0.16-0.2mm - you want clean smooth prints!

- Infill should be 40%+ Gyroid

# Wiring

- 5v+ to switch NC (Normally Closed)

- v- & LED cathode to switch NO (Normally Open)

- Signal & LED anode (with resistor) to switch C or Comm (Common)

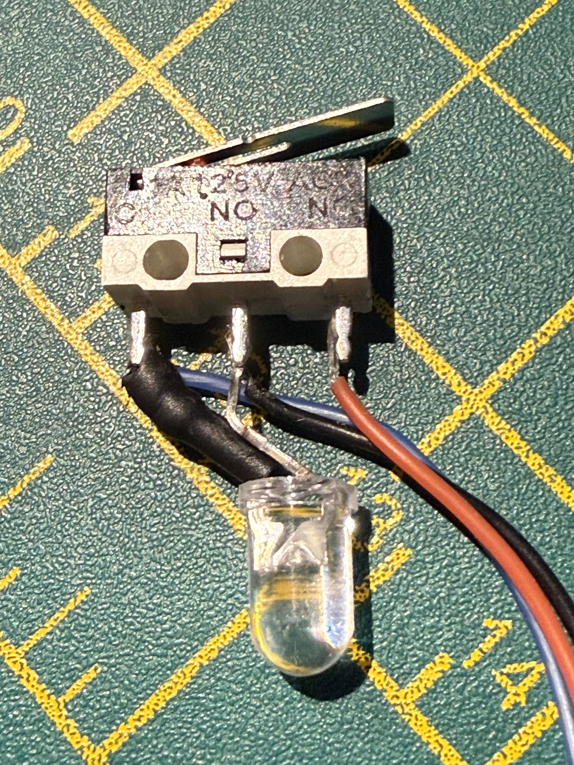
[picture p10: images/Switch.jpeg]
Switch
  

# Dock Assembly

- Pass wires through hole in mounting face

- Insert LED first nearest the bottom of the dock

- Make sure the switch lever is facing DOWNWARDS & not up!!

- Gently ease the parts together checking the wires DO NOT get pinched or damaged

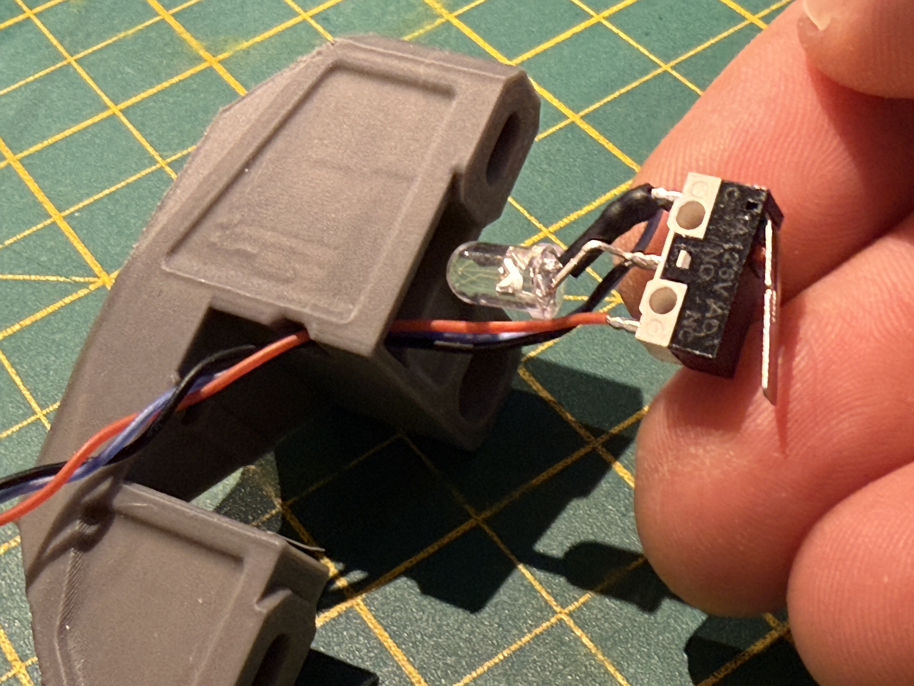
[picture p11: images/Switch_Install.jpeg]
Switch_Install
  

- When fully seated the system should look like this! The switch body MUST be BELOW the surface of the switch mounting recess!

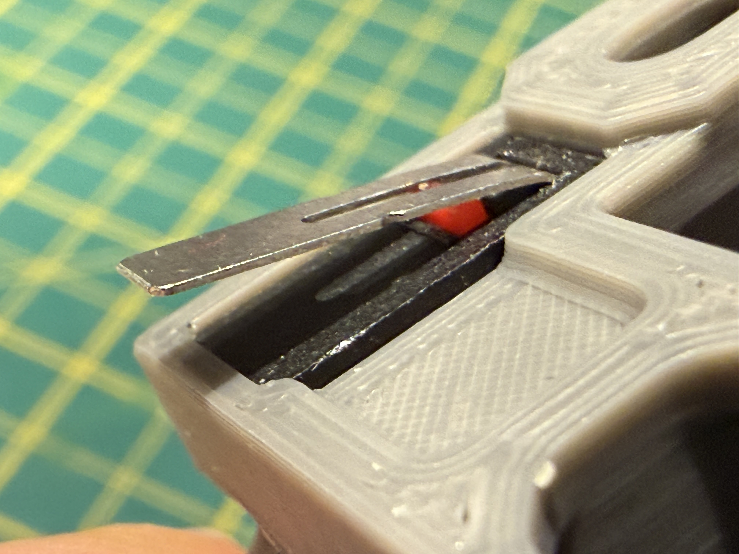
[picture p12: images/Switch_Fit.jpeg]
Switch_Fit
  

# Install magnets

Be sure to get the polarity correct!! Use a spare tool & add the magnets you intend to use & add them to the end of the tool's magnets so the they sit the correct way. Now offer the new magnets to your new docks & VERY CAREFULLY insert them into the holes in the dock. If they don't fit, it's probably the print, use the FMD specified model then or take a 3mm drill bit & expand the holes slightly. You'll probably have to use super glue if you do this. It's better to get a good fit & not drill them out.

Finish up by installing the rest of the standard Bontech dock hardware.

# Connect

Add plugs for your chosen MCU making sure the connections are correct for the board. Don't let the runs of wires get muddled. Twist each set of wires from each switch together as you go & tie a loose knot in the end while you're working. This will stop power from switch 7 getting hooked up to plug 0 or signal from switch 4 going to switch 2 for example! Keep things organised!

# Klipper setup

- Include the `DEMON_DOCKS.cfg` file & set your serial ID & switch count

- Include the `DEMON_DOCK_GUARDIANS.cfg` file

- open index.cfg & set `variable_demon_docks: True`

## If your Load Cell settings need changing...

- Home the printer then with a tool still loaded send...

```
LOAD_CELL_CHECK
```

- After the reading is shown in the console, look for the first number ending (g) `Load cell force`. So for example "Load cell force 138.0g" & add it to `variable_lc_loaded:`
  NOTE: the number doesn't have to be exactly the same as we have a wide tolerance range so 140 would be fine, we're looking for a rough average in the readings.

- Next `PARK_TOOL` so the toolhead is empty then send

```
LOAD_CELL_CHECK
```

- After the reading is shown in the console, look for the first number ending (g) `Load cell force`. So for example "Load cell force 1674.2g" & add it to `variable_lc_empty:`
  NOTE: the number doesn't have to be exactly the same as we have a wide tolerance range so 1700 would be fine, we're looking for a rough average in the readings.

- Save & Restart

# Testing the Docks

- The LED should light when a tool is removed & the console should tell you an inactive tool has been removed.

- The LED should go out when a tool is docked, there will be no console message.

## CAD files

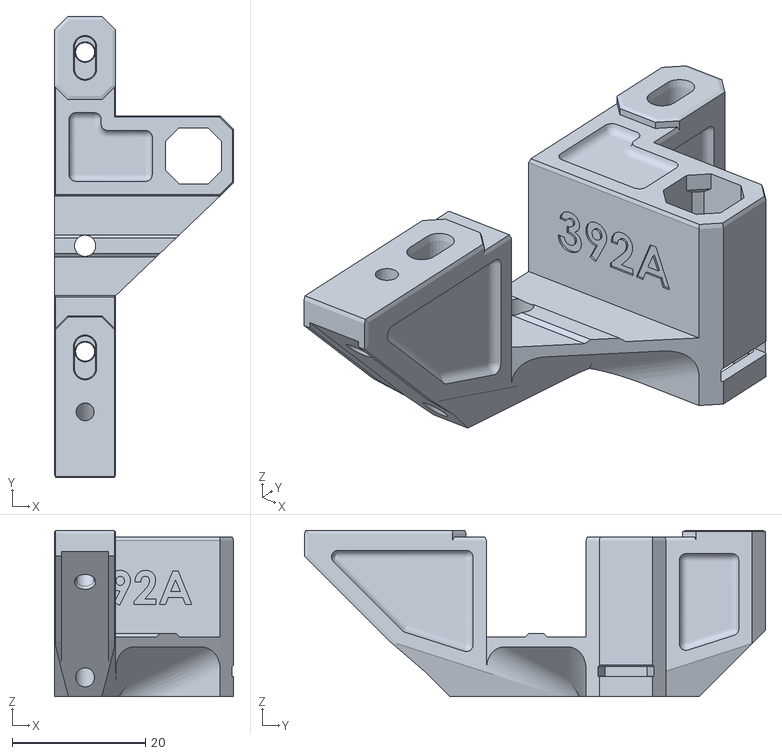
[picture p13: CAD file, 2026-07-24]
CAD/STL/INDX Tool Dock 1515 Main body.stl
26.9 x 69.3 x 25.0

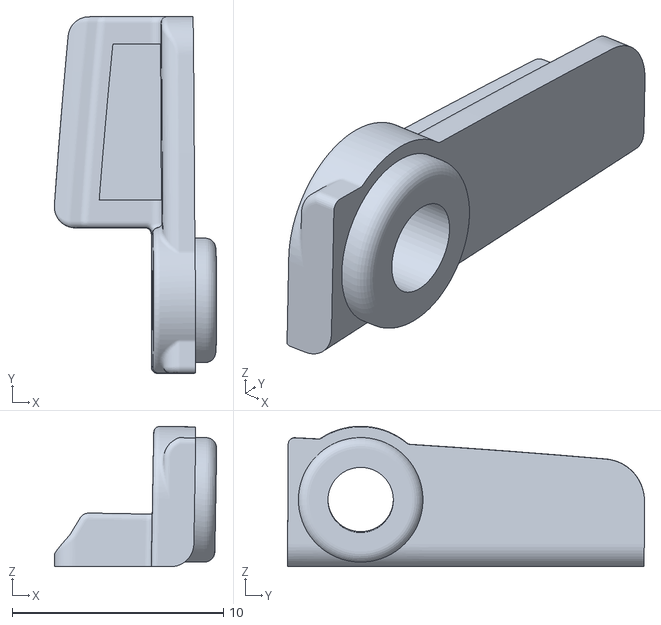
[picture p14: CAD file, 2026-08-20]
CAD/STL/INDX_Part_Cooling_Interface_left.stl
7.70 x 16.9 x 6.66

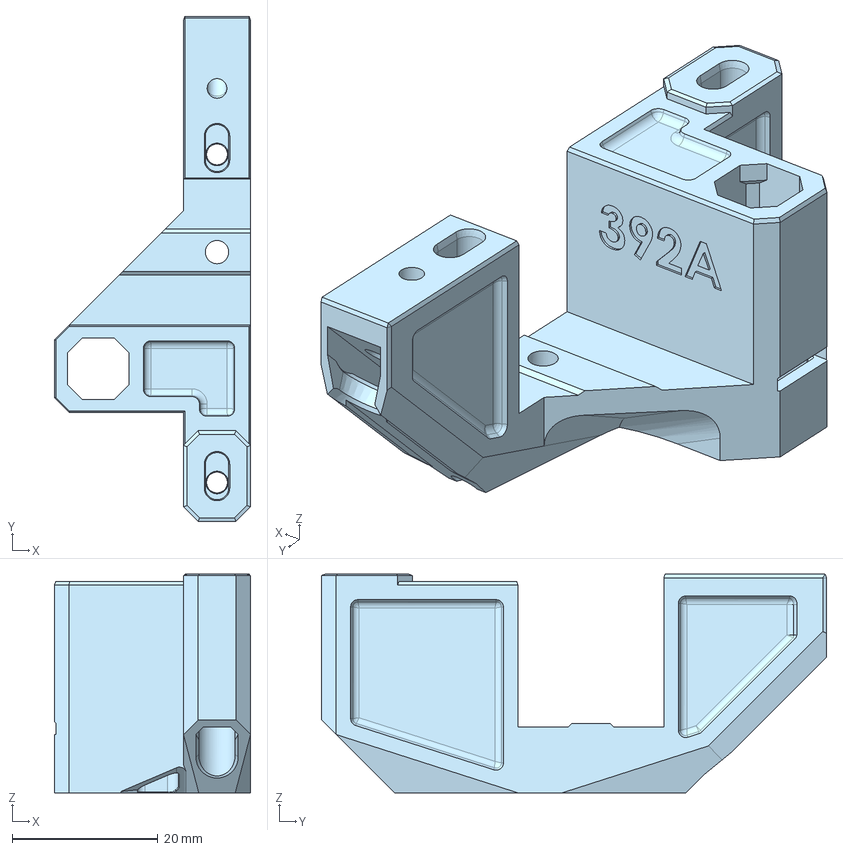
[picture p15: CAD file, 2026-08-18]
community/1_printer_agnostic/2020-dock/CAD/dock_2020_1x.step
26.9 x 69.3 x 30.0 mm

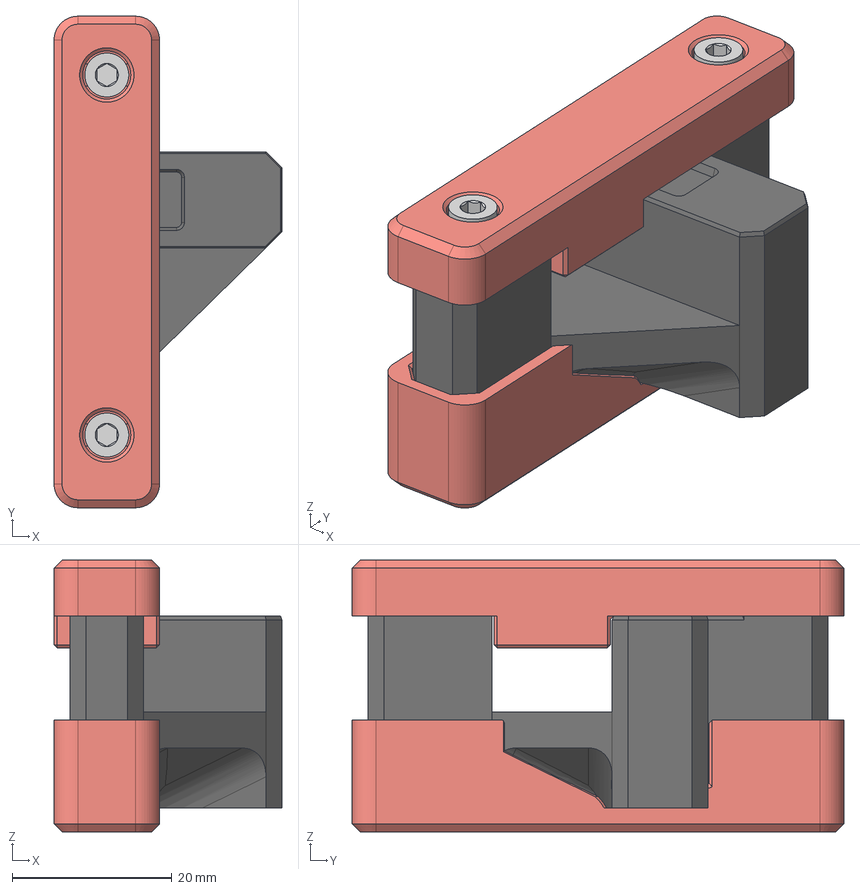
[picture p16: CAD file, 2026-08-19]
community/1_printer_agnostic/magnet-jig/CAD/tool_holder_magnet_jig.step
28.5 x 61.4 x 34.0 mm
Magnet_Jig_A
Magnet_Jig_B
M3x8 SHCS x 2

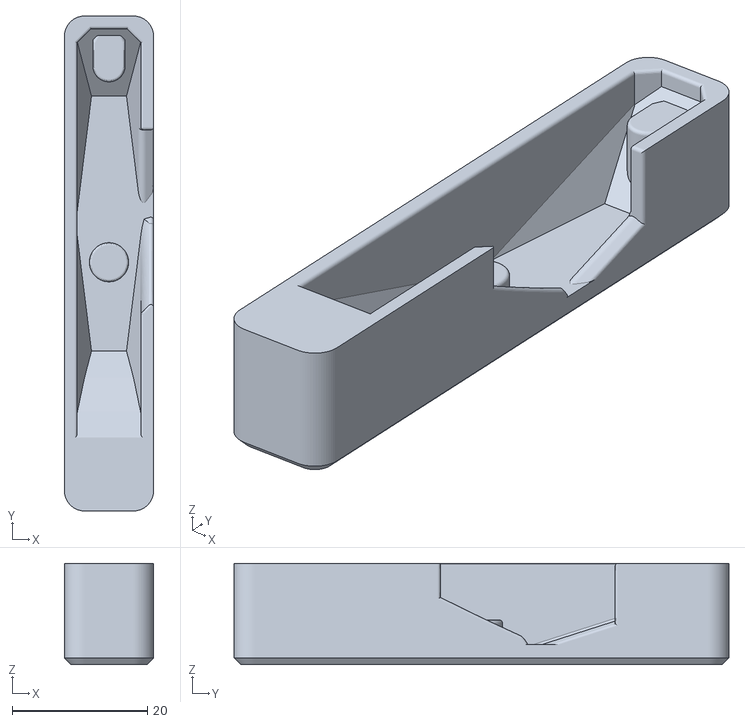
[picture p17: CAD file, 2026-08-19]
community/1_printer_agnostic/magnet-jig/indx_th_mag_tool_a.stl
13.2 x 73.3 x 15.0

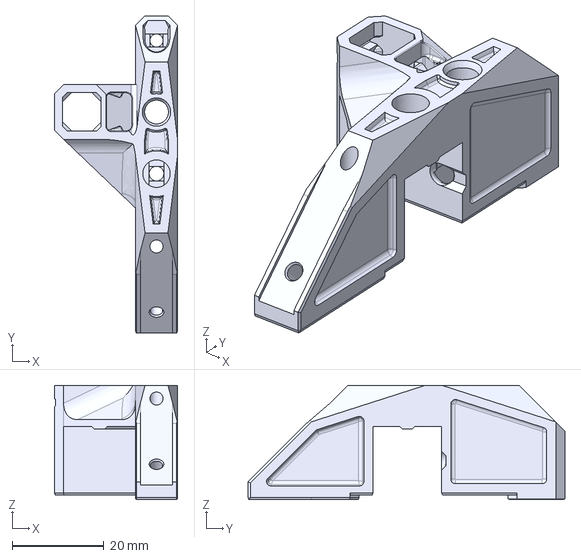
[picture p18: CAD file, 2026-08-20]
DEMON Docks/CAD/INDX DEMON Dock D2F-5L.step
26.9 x 69.3 x 25.0 mm

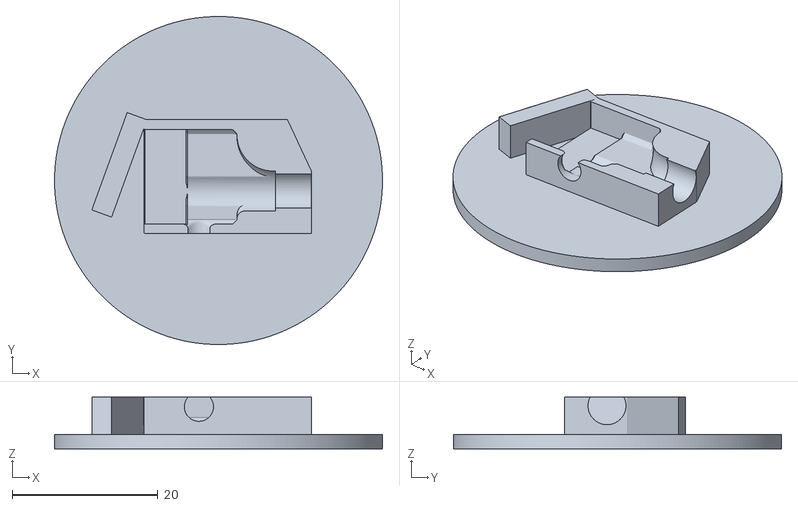
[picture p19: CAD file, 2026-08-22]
DEMON Docks/DEMON DOCKS Soldering Jig.stl
45.0 x 45.0 x 7.12

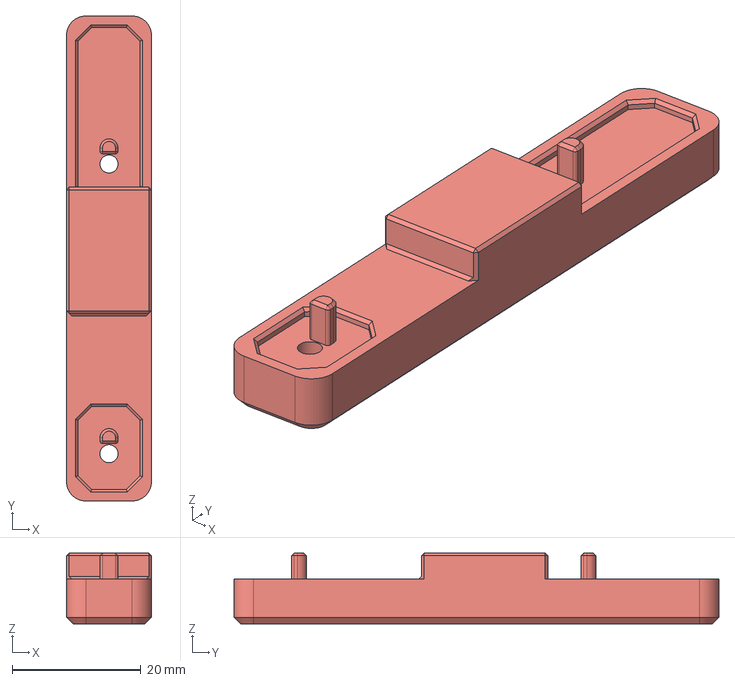
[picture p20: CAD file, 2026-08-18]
community/1_printer_agnostic/2020-dock/CAD/magnet_jig_bottom_1x.step
13.2 x 75.3 x 11.0 mm

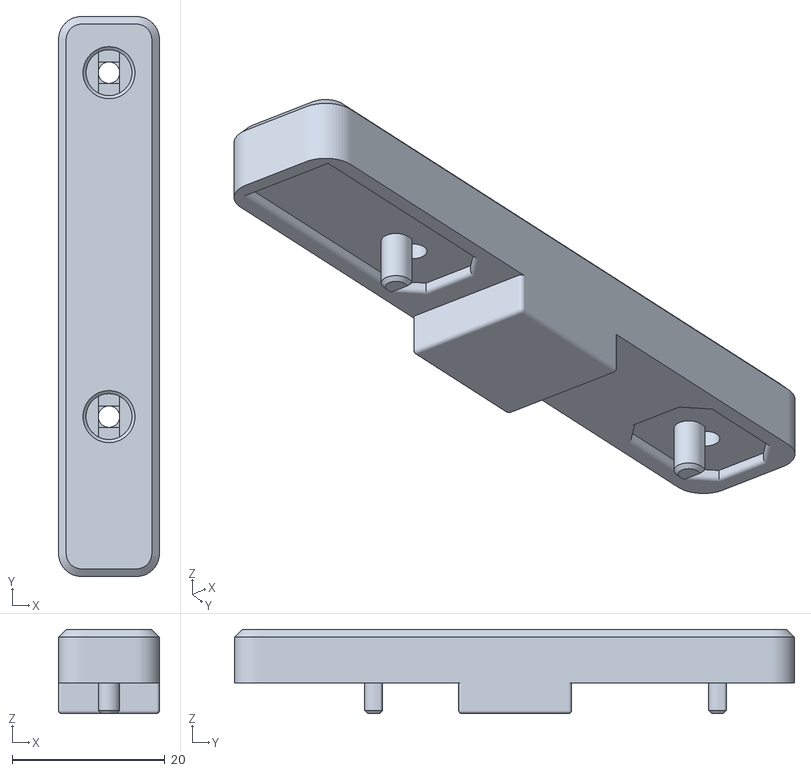
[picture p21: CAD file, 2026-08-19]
community/1_printer_agnostic/magnet-jig/indx_th_mag_tool_b.stl
13.2 x 73.3 x 11.0

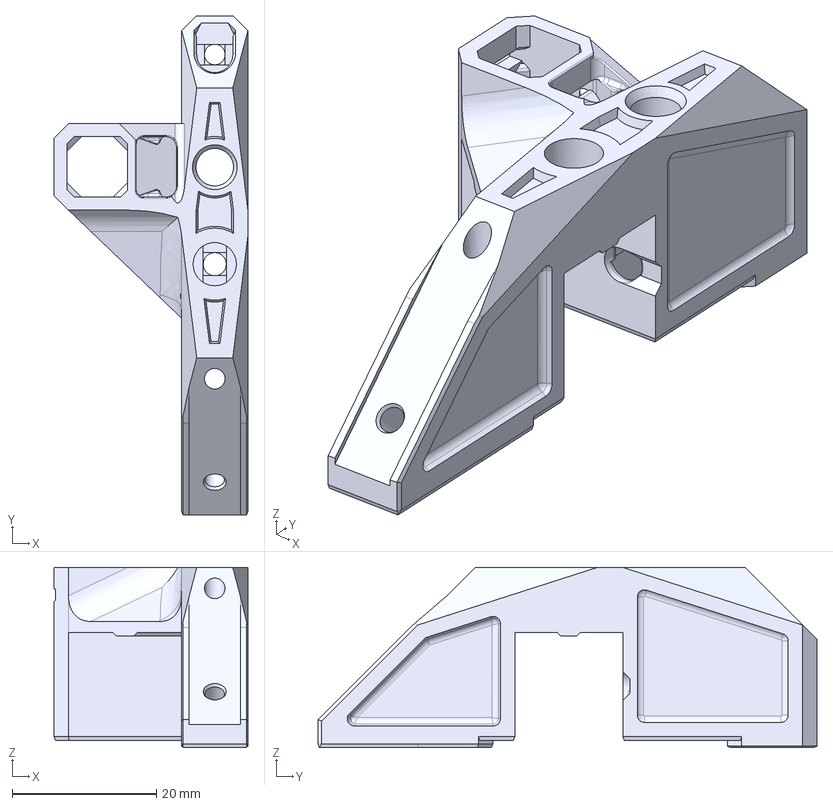
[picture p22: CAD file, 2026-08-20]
DEMON Docks/CAD/INDX DEMON Dock D2F-5L FDM.step
26.9 x 69.3 x 25.0 mm

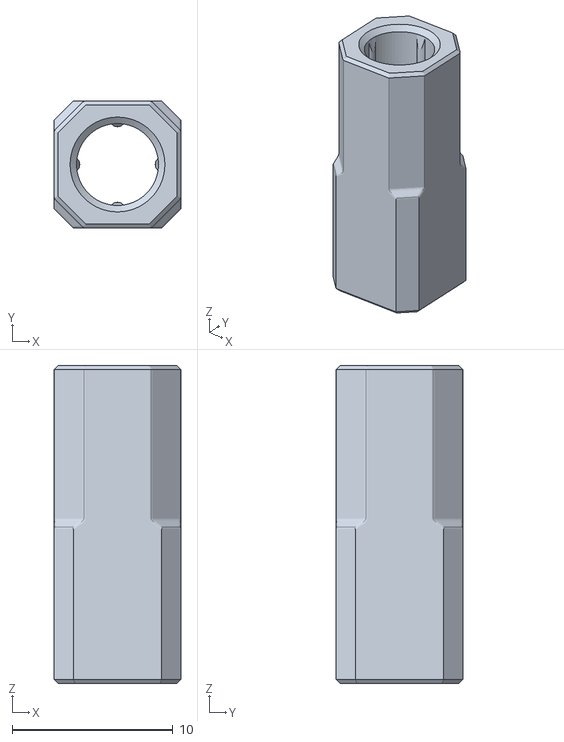
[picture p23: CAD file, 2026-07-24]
CAD/STL/INDX Tool Dock 1515 Magnet holder.STL
7.90 x 7.90 x 19.8

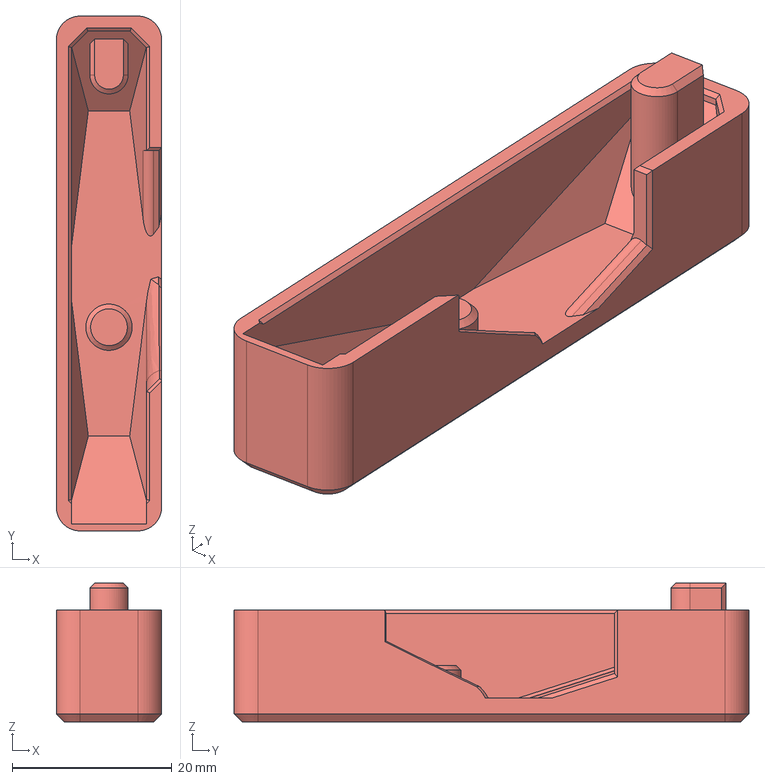
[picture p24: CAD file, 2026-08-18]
community/1_printer_agnostic/2020-dock/CAD/magnet_jig_top_1x.step
13.2 x 64.4 x 17.4 mm

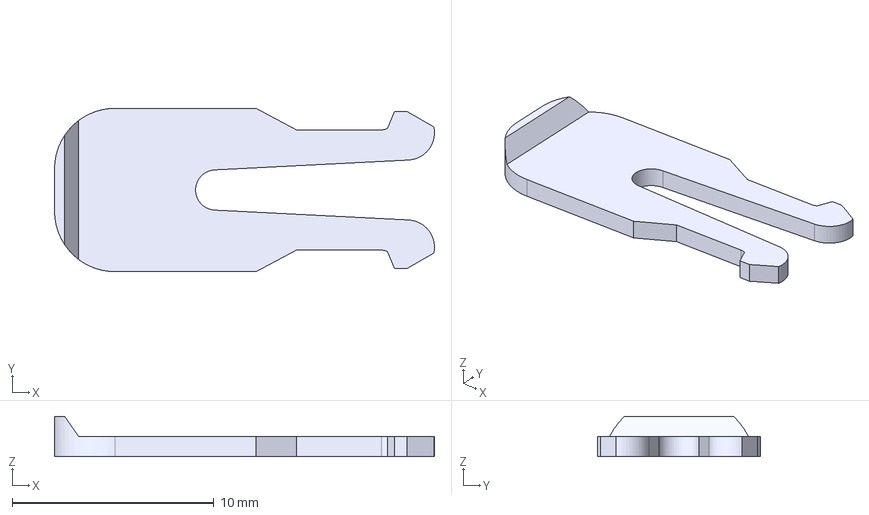
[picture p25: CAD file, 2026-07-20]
community/1_printer_agnostic/2020-dock/CAD/[a]_spring_lid_1x.step
18.9 x 8.10 x 2.00 mm

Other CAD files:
CAD/STL/INDX_Part_Cooling_Interface_right.stl
DEMON Docks/DEMON DOCK D2F-5L FDM.stl
DEMON Docks/DEMON DOCK D2F-5L.stl
CAD/STL/INDX Tool Dock 1515 Spring lid.stl
community/1_printer_agnostic/2020-dock/CAD/[a]_magnet_holder_1x.step
community/1_printer_agnostic/2020-dock/CAD/magnet_insertion_tool_1x.step
community/1_printer_agnostic/2020-dock/[a]_magnet_holder_1x.stl
community/1_printer_agnostic/2020-dock/[a]_spring_lid_1x.stl
community/1_printer_agnostic/2020-dock/dock_2020_1x.stl
community/1_printer_agnostic/2020-dock/magnet_insertion_tool_1x.stl
community/1_printer_agnostic/2020-dock/magnet_jig_bottom_1x.stl
community/1_printer_agnostic/2020-dock/magnet_jig_top_1x.stl
community/1_printer_agnostic/magnet-jig/CAD/tool_holder_magnet_jig.f3d

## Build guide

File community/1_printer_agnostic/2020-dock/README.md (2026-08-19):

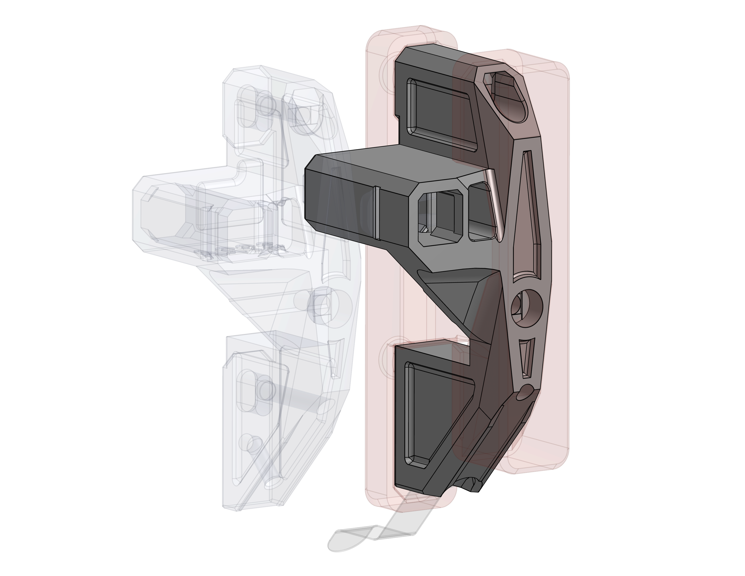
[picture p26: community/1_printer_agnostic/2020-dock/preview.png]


Imported dock from Bondtech's simplified geometry. Through a long series of cuts and small adjustments the dock was beefed up to fit on a 2020 extrusion. It still uses the same exact hardware and other printed parts, only the body was changed. ([Onshape source](https://cad.onshape.com/documents/78836e2fa75979653fb6a091/w/3316e982cf645299c83fd133/e/2c345297b517125cc0666689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))

The dock has 5mm of additional thickness compared to the original 1515 dock to make it similarly sturdy. It has the same dimensions on all other axes.

There really isn't any reason to use this dock other than "I had a spare 2020 extrusion and didn't want to buy a 1515"

There's also an adapted version of the [1515 dock magnet jig](../magnet-jig/README.md) to fit the new dock geometry.

# Assembly

See [1515 dock magnet jig](../magnet-jig/README.md)

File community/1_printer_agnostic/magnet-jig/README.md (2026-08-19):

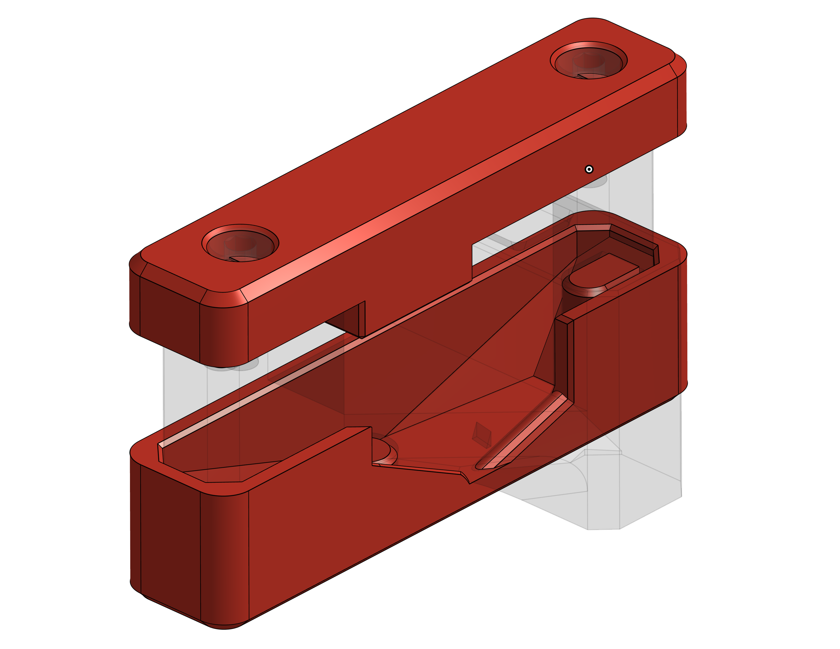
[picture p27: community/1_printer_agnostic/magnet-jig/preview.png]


[Printables Source](https://www.printables.com/model/1761126-bondtech-indx-toolholder-magnet-tool)

Uses 2x M3x8 SHCS. If you don't want your life to be hell **USE MAGNETIC SCREWS**.

## Assembly

1. Screw out both magnet jig screws until they are just barely peeking out.
2. Snap both small magnets to a passive tool to get their correct orientation
3. Pick up one magnet and snap it onto the screw, **with the same side that previously attached to the dock**.
   You can imagine the jig as being a passive tool here.
4. **Triple check magnet orientation**. Pointing the magnet towards the passive tool's magnets you should feel them repelling each other.
5. Use a pipe wrench to press-fit the magnet just enough to where it holds by itself (doesn't fall out)
6. Quadruple check the orientation (aka test-fit the passive tool) **BEFORE FULLY PRESS-FITTING THE MAGNETS**
7. Iteratively fully-insert the magnets
   1. Screw the magnet in by 0.5-1mm
   2. Use a pipe wrench to press down the magnet fully
   3. Repeat until the screw is fully screwed in
8. Use a magnetic M3x6 SHCS to push the magnets down a few fractions of a millimeter more,
   so that the passive tool's magnets don't directly touch the dock's magnets anymore
9. Repeat for the second magnet

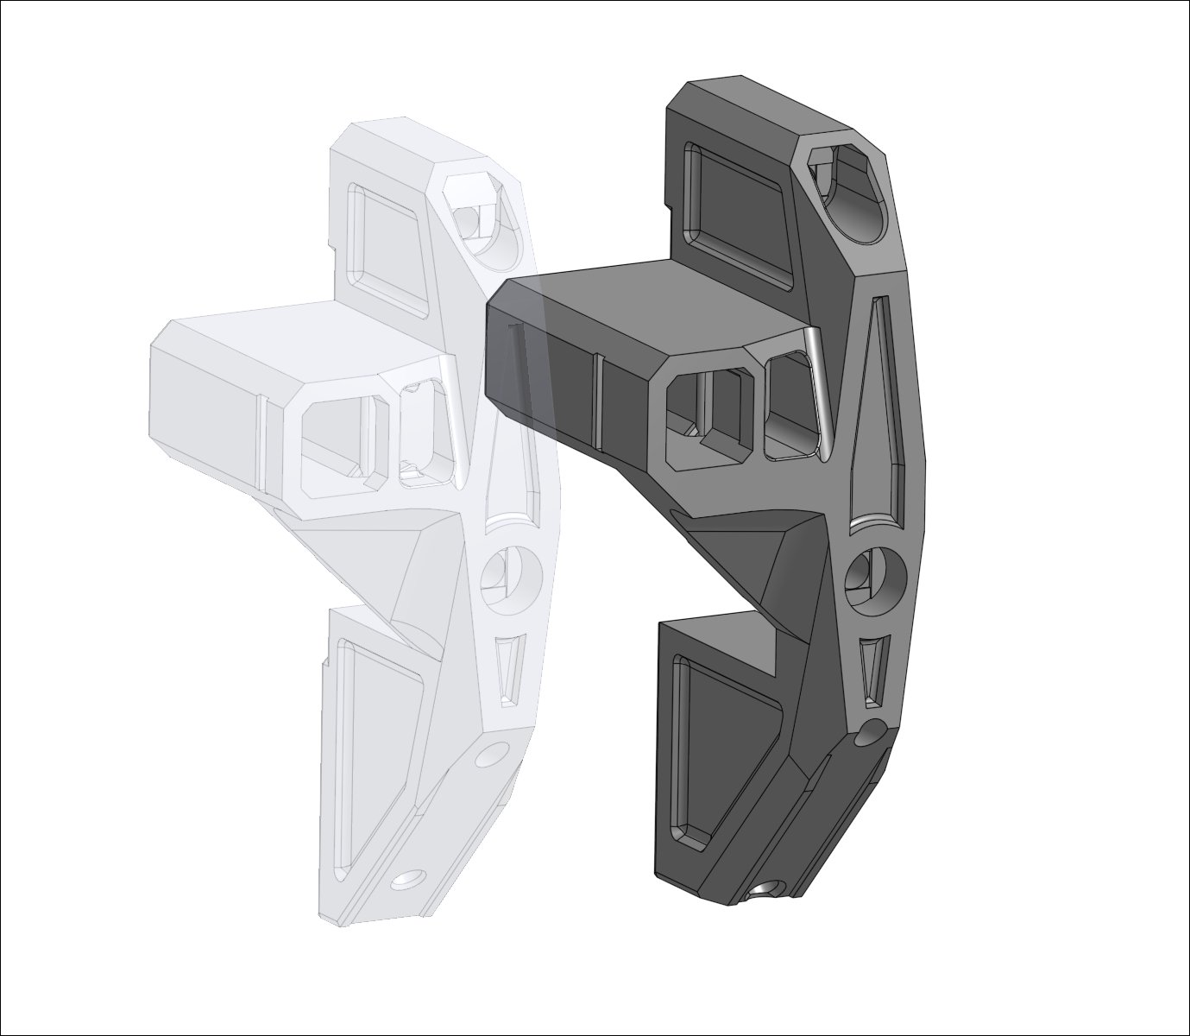
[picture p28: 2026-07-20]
community/1_printer_agnostic/2020-dock/preview.jpg

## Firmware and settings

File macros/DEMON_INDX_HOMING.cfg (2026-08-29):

###################################################
#######>>>>>>>>>>  3DPrintDemon  <<<<<<<<<<<#######
#######   https://github.com/3DPrintDemon   #######

[homing_override]
axes: xyz
gcode:
  	{% set home_all = 'X' not in params and 'Y' not in params and 'Z' not in params %}

  	{% set st = printer["gcode_macro _TOOLCHANGE_VARS"].toolhead_state|int %}
  	{% set act = printer.save_variables.variables.active_tool|default(-1)|int %}

  	{% if (act != -1 and st == 2) or (act == -1 and st != 2) %}
    	{action_raise_error("⚠️ WARNING! Homing cancelled, your INDX toolhead state is misconfigured. Active tool & toolhead state are not aligned! Run TOOL_STATUS to check!")}
  	{% endif %}
        
    RESPOND TYPE=COMMAND MSG="Homing requested"
    

    {% if 'z' not in printer.toolhead.homed_axes %}
      	{% if 'x' not in printer.toolhead.homed_axes or 'y' not in printer.toolhead.homed_axes %} 
        	{% if 'Z' in params %}
          		{ action_raise_error("Request denied, operation cancelled! Home X & Y axes first before requesting homing Z") }

        	{% else %}
          		{% if 'x' in printer.toolhead.homed_axes or 'y' in printer.toolhead.homed_axes %}
        
          		{% else %}
            		# RESPOND TYPE=COMMAND MSG="Raising Z axis for safe clearance prior to homing"
            		_Z_LIFT

          		{% endif %}
        	{% endif %}  
      	{% endif %}

	{% else %}
      	{% if printer.toolhead.position.z|float < 5 %}
        	RESPOND TYPE=COMMAND MSG="Z axis <5mm. Raising for safe clearance prior to homing"
        	_Z_LIFT
      	{% endif %} 
    {% endif %}  

    {% if home_all or 'Y' in params %}
        _HOME_Y
    {% endif %}
    
    {% if home_all or 'X' in params %}
        _HOME_X
    {% endif %}

   

    # Add this to homing_override Z section to work with 3DPD modified indx-tc-macros.cfg file 😈
    {% if home_all or 'Z' in params %}
        {% set st = printer["gcode_macro _TOOLCHANGE_VARS"].toolhead_state|int %}
        {% set act = printer.save_variables.variables.active_tool|default(-1)|int %}

        {% set x_pos = (printer.toolhead.axis_maximum.x / 2)|int %}
        {% set y_pos = (printer.toolhead.axis_maximum.y / 2)|int %}
        {% set rand_x = range((x_pos - 15|int), (x_pos + 15|int))|random %}
        {% set rand_y = range((y_pos - 15|int), (y_pos + 15|int))|random %}


        # checks if toolhead is empty when using the load cell, picks up a tool first before homing Z if empty
        {% if 'load_cell_probe' in printer and (act == -1 or st == 2) %}
            RESPOND TYPE=COMMAND MSG="⚠️ Toolhead empty! Homing XY so I can pickup a tool to home Z!"
            CHANGE_TOOL TOOL=0
            M400
            {% if printer.load_cell_probe.is_calibrated %}
                G90             
                G0 X{printer.toolhead.axis_maximum.x|float / 2} Y{printer.toolhead.axis_maximum.y|float / 2} F6000
                G28 Z 
                M400
            {% endif %}

        # if using the load cell & it is calibrated & the toolhead is carrying a tool move & home Z, also do this if load cell not defined
        {% elif ('load_cell_probe' in printer and printer.load_cell_probe.is_calibrated) or 'load_cell_probe' not in printer %}
            G90    
            # {% if act != 0 %}
            #   CHANGE_TOOL TOOL=0
            # {% endif %}

            G0 X{rand_x|int} Y{rand_y|int} F6000
            
            M400
            
            G28 Z 
            M400
        {% endif %}

        G0 Z20 F3600  
    {% endif %}

	M117
    G90
  



[gcode_macro _HOME_X]
gcode:
	SET_TMC_CURRENT STEPPER=stepper_x CURRENT=0.8
    SET_TMC_CURRENT STEPPER=stepper_y CURRENT=0.8
    M400

    G28 X
    G91
    {% if printer.configfile.settings.stepper_x.homing_positive_dir == False %}
        G0 X20 F3000
    {% else %}
        G0 X-20 F3000
    {% endif %}
    
    G90
    G4 P2000
    M400

    {% set cf = printer.configfile.config %}
    {% set driver_x = ["tmc2209 stepper_x", "tmc5160 stepper_x", "tmc2208 stepper_x", "tmc2226 stepper_x", "tmc2225 stepper_x", "tmc2130 stepper_x", "tmc2240 stepper_x", "tmc2660 stepper_x"] %}
    {% set driver_y = ["tmc2209 stepper_y", "tmc5160 stepper_y", "tmc2208 stepper_y", "tmc2226 stepper_y", "tmc2225 stepper_y", "tmc2130 stepper_y", "tmc2240 stepper_y", "tmc2660 stepper_y"] %}

  	{% for s in driver_x %}
    	{% if s in cf %}
            {% set run_x = cf[s].run_current|float %}
            # RESPOND TYPE=COMMAND MSG="X Stepper {s} run current {run}a
            SET_TMC_CURRENT STEPPER=stepper_x CURRENT={run_x}
        {% endif %}
    {% endfor %}

  	{% for s in driver_y %}
      	{% if s in cf %}
            {% set run_y = cf[s].run_current %}
            # RESPOND TYPE=COMMAND MSG="Y Stepper {s} run current {run}a
            SET_TMC_CURRENT STEPPER=stepper_y CURRENT={run_y}
        {% endif %}
    {% endfor %}

    M400 
    



[gcode_macro _HOME_Y]
gcode:
	SET_TMC_CURRENT STEPPER=stepper_x CURRENT=0.8
    SET_TMC_CURRENT STEPPER=stepper_y CURRENT=0.8
    M400

    G28 Y
    G91
    {% if printer.configfile.settings.stepper_y.homing_positive_dir == False %}
        G0 Y20 F3000
    {% else %}
        G0 Y-20 F3000
    {% endif %}
    
    G4 P2000
    M400

	{% set cf = printer.configfile.config %}
    {% set driver_x = ["tmc2209 stepper_x", "tmc5160 stepper_x", "tmc2208 stepper_x", "tmc2226 stepper_x", "tmc2225 stepper_x", "tmc2130 stepper_x", "tmc2240 stepper_x", "tmc2660 stepper_x"] %}
    {% set driver_y = ["tmc2209 stepper_y", "tmc5160 stepper_y", "tmc2208 stepper_y", "tmc2226 stepper_y", "tmc2225 stepper_y", "tmc2130 stepper_y", "tmc2240 stepper_y", "tmc2660 stepper_y"] %}

  	{% for s in driver_x %}
      	{% if s in cf %}
            {% set run_x = cf[s].run_current|float %}
             # RESPOND TYPE=COMMAND MSG="X Stepper {s} run current {run_x}a"
            SET_TMC_CURRENT STEPPER=stepper_x CURRENT={run_x} 
        {% endif %}
    {% endfor %}

  	{% for s in driver_y %}
      	{% if s in cf %}
            {% set run_y = cf[s].run_current %}
            # RESPOND TYPE=COMMAND MSG="Y Stepper {s} run current {run_y}a"
            SET_TMC_CURRENT STEPPER=stepper_y CURRENT={run_y}    
        {% endif %}
	{% endfor %}

    M400



[gcode_macro _Z_LIFT]
gcode:
  	{% set start_vars = printer["gcode_macro _START_VARIABLES"] %}
  	{% set core_vars = printer["gcode_macro _CORE_VARS"] %}
          
  	{% if 'z' not in printer.toolhead.homed_axes %}
    	RESPOND TYPE=COMMAND MSG="Raising Z axis for safe clearance prior to homing"
      	RESPOND TYPE=COMMAND MSG="WARNING AXES RESET FOR Z LIFT!!"
      	SET_KINEMATIC_POSITION X=0 Y=0 Z=0 SET_HOMED=Z
      	G90
      
        G0 Z10 F3000
        M400
        # RESPOND TYPE=COMMAND MSG="Disabling axes"

        SET_KINEMATIC_POSITION SET_HOMED= CLEAR_HOMED=XYZ
        M84
    
  	{% else %}
      	G90
        RESPOND TYPE=COMMAND MSG="Raising Z axis for safe clearance prior to homing"
        G0 Z10 F3000
        M400
  	{% endif %}

      
    

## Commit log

2026-07-20 feat: add 2020 dock
    [[a]_magnet_holder_1x.step, [a]_magnet_holder_1x.stl, [a]_spring_lid_1x.step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]
2026-07-24 Add files via upload
    Updated the geometry of the Magnet holder in order to avoid cracking, should be printed in a standing orientation.
    [INDX Tool Dock 1515 Magnet holder.STL, INDX Tool Dock 1515 Main body.stl, INDX Tool Dock 1515 Spring lid.stl]
2026-07-25 fix: macros - correct gcode offset handling around _TC_G0
    [indx-tc-macros.cfg]
2026-07-25 feat: new magnet jig
    [magnet_insertion_tool_1x.stl, magnet_jig_bottom_1x.step, magnet_jig_bottom_1x.stl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]
2026-08-08 fix: macros - use correct TMC chopper field on MODE_*
    en_spreadcycle only exists on TMC2208/2209; other XY drivers need
    en_pwm_mode with inverted polarity. Detect the driver once at boot
    and apply it to all present XY steppers including AWD x1/y1.
    [indx-tc-macros.cfg]
2026-08-10 fix: macros - bake live babystep on Z apply
    Mainsail/Fluidd only change homing_origin.z, so reading
    save_variables alone cleared the tweak and baked nothing.
    [indx-cal.cfg]
2026-08-17 fix: detect XY TMC driver per stepper on MODE_*
    Replace the boot-cached driver prefix with a per stepper lookup in
    _SET_MODE, so machines that mix driver families across X/Y and the AWD
    stepper_x1/y1 get the correct chopper field on every stepper instead of
    only the ones matching the first driver found.
    Also report when no supported XY driver is configured, rather than
    silently leaving the chopper mode untouched.
    [indx-tc-macros.cfg]
2026-08-17 Copy fixes on the merged doc tips
    Grammar in the dock alignment pro tip, and the OrcaSlicer setting is
    called Change filament G-code, not Change filament change G-code.
2026-08-17 Document the Klipper sections INDX requires
    save_variables and respond are used throughout the macros but were
    never mentioned in the setup instructions, so a missing section only
    showed up as a runtime failure later on.
    Fixes #18
2026-08-17 Follow-ups on the merged calibration fixes
    Drop the 4 s dwell added alongside the TEMPERATURE_WAIT window in #20 —
    the widened window is what fixes the hang, and the extra wait was
    unexplained. Raised on the PR.
    Report when there is no global Z to bake rather than staying silent,
    so APPLY_PROBE always says what it did.
    Grammar in the CAL_Z filament prerequisite.
    [indx-cal.cfg]
2026-08-17 Wait for tool temperature after pickup
    _PICKUP_TOOL set the target with M104 and returned immediately, so a
    toolchange completed while the newly picked tool was still cold and the
    print could resume straight into a cold extrusion.
    M109 has a 1 C settle band rather than the strict minimum that made
    TEMPERATURE_WAIT hang in #19, so this does not reintroduce that.
    Fixes #16
    [indx-tc-macros.cfg]
2026-08-17 Document the load cell probe config
    The load cell is the Z probe but printer.cfg never showed how to
    configure it, so there was no way to get a working [load_cell_probe]
    section from the docs alone.
    Notes that counts_per_gram and reference_tare_counts come out of
    calibration rather than being set by hand, which is the part that
    made this circular.
    Fixes #17
2026-08-17 Expand the load cell probe docs
    Add pullback_distance and pullback_speed from the config in #17, plus
    sample_rate, and explain what the pullback move is for.
    Flag that the section is Kalico specific: mainline Klipper ships a
    different load_cell_probe that has no pullback options and rejects
    force_safety_limit values below 100.
    Also document the register_as_probe change needed when a Beacon or
    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
2026-08-17 Document the swapped USB DP+/DP- labels
    The pin marked DP+ is electrically DP- and vice versa, so wiring a USB
    accessory by the printed labels fails to enumerate. Two users hit this
    independently with Cartographer probes.
    Warns at both pinout tables and adds a wiring table by function, since
    the silkscreen and the pinout image both carry the wrong labels.
    Fixes #24
2026-08-17 Correct the dock alignment image captions
    Both images show the printed alignment jig, but their alt text still
    described the older extra-magnet method. That text is what readers see
    whenever an image fails to load, so it needs to match the picture.
2026-08-17 Commit the six installation images and drop the magnet set
    The fan shroud and Tool Dock Activator steps referenced images that
    were never in the repo — they pointed at GitHub attachment assets from
    a private tracker, so they rendered only for people with access to it
    and were broken for everyone else.
    The files are now committed and referenced by relative path. Also
    removes the two extra-magnet dock alignment images, superseded when
    that procedure was rewritten around the printed jig.
    Fixes #14
2026-08-17 Fail CI on documentation images that are not committed files
    Catches both ways this breaks: an image hot-linked to an external URL,
    and a relative path pointing at a file that is not in the repo.
    The first is the one worth guarding. A pasted GitHub attachment link
    renders correctly for whoever pasted it and breaks for readers without
    access to the source, so it cannot be spotted by the person able to
    fix it.
2026-08-18 Document CPAP part cooling calibration
    A CPAP blower configured with off_below reports no cooling at every
    commanded speed under the threshold, which is exactly where the fan
    model is most sensitive because it fits a negative exponent. The fit
    comes out wrong across the whole range, the model diverges once real
    cooling starts, and the printer shuts down about a minute into the
    print.
    Covers using min_power instead, the calibration order, calibrating
    with the hose attached at print height, and why raising
    max_model_error is the wrong response.
2026-08-18 Track filament model params per tool
    INDX_SET_MODEL_PARAMS was only ever called at load time and never
    re-applied on a toolchange, so the safety model held whichever material
    was loaded last on any tool. On a multi-material print that is the
    wrong filament for most of the job, and the filament heat loss term is
    proportional to flow rate.
    LOAD_FILAMENT now records density and heat capacity against the tool,
    and every pickup restores them before the tool heats. SET_TOOL_FILAMENT
    exposes the same thing directly. Tools with nothing recorded leave the
    model alone, so existing setups are unaffected.
    [indx-cal.cfg, indx-tc-macros.cfg]
2026-08-18 Fix a comment that broke template compilation
    The comment added in #7 warning about the bare-minus form contained
    that form literally. Klipper hands the whole macro body to Jinja,
    comments included, so the warning parsed as an expression and every
    config using these two macros failed to load.
    Rephrased so it says the same thing without writing the sequence out.
    [indx-cal.cfg, indx-tc-macros.cfg]
2026-08-18 Compile every macro template in CI
    A macro that fails to compile stops Klipper from starting, so it is a
    dead printer at boot rather than a runtime warning. #7 shipped one
    briefly and only a manual check caught it.
    Uses the same delimiters as Klipper's gcode_macro, including the part
    that caught us out: # comments are not stripped before compilation, so
    a Jinja delimiter written inside a comment is still parsed.
2026-08-18 feat: update dock
    [dock_2020_1x.step, dock_2020_1x.stl]
2026-08-18 feat: magnet jig
    [indx_th_mag_tool_a.stl, indx_th_mag_tool_b.stl, tool_holder_magnet_jig.f3d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]
2026-08-20 Separate the Z hop from XY travel during toolchanges
    The hop was folded into the first XY move so the axes ran together.
    A coordinated move raises Z gradually across the whole travel, so the
    nozzle is still at print height when XY starts moving and drags across
    the part. The return path was worse: Z descended while the head was
    still sprinting back over the print area.
    Z now clears and lands before any XY travel, and on the way back drops
    only after XY has reached the clearance line. Costs a fraction of a
    second per change for not scraping the print at both ends.
    Reported by 3DPrintDemon and Schmudus.
    [indx-tc-macros.cfg, indx.cfg]
2026-08-20 Correct the 40x10 part cooling fans to radial
    They are radial blowers, not axial. The CAD file table further down
    already described them as blower ducts, so the document contradicted
    itself.
2026-08-20 Add the part cooling interface pieces
    These are the fan shroud clips that attach a shroud to the left and
    right Front Covers. The installation steps already told people to fit
    one, but the file was never in the repo, so there was nothing to print.
    Listed in the CAD table and referenced from the installation steps,
    which now also make it clear there is a left and a right.
    [INDX_Part_Cooling_Interface_left.stl, INDX_Part_Cooling_Interface_right.stl]
2026-08-20 add macro files
    [indx-cal.cfg, indx-tc-macros.cfg, indx.cfg]
2026-08-20 Add demon dock macros and update indx configs
    [DEMON_DOCKS.cfg, DEMON_DOCK_GUARDIANS.cfg, DEMON_INDX_EXTRAS.cfg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]
2026-08-21 Let the slicer pass the incoming tool's temperature
    CHANGE_TOOL captured the outgoing tool's target and heated the new tool
    to it. That is right when both tools print at the same temperature and
    wrong when they do not, and since the pickup now waits on that target,
    a change from a hotter to a cooler material overheats the new tool and
    then waits for it to cool back down.
    TEMP= supplies the incoming tool's own target. Without it the previous
    behaviour is unchanged, so existing slicer configs keep working.
    The OrcaSlicer snippet had no temperature handling at all, unlike the
    PrusaSlicer one, which is why this only showed up there.
    [indx-tc-macros.cfg]
2026-08-21 TC_GO Changes
    [indx-tc-macros.cfg]
2026-08-21 Use a verified load cell probe configuration
    Replaces the assembled example with one 3DPrintDemon has running on a real
    machine. Slower approach and retry speeds, a three sample median rather
    than a single probe, a longer pullback, and a non zero z_offset.
    The z_offset is now called out as a per machine value. The nozzle is
    the probe so there is no probe to nozzle distance, but the tool still
    deflects under trigger force and that has to come out somewhere.
    Config verified and contributed by 3DPrintDemon.
2026-08-21 Refactor ZHOP handling and comments in indx-tc-macros.cfg
    Removed redundant comments and adjusted the placement of the M400 command for better clarity.
    [indx-tc-macros.cfg]
2026-08-21 Update TC logic
    [indx-tc-macros.cfg]
2026-08-21 Update for use without DEMON_DOCKS files, will still require Demon indx.cfg
    [indx-tc-macros.cfg]
2026-08-22 Add DEMON DOCKS Soldering Jig stl
    [DEMON DOCKS Soldering Jig.stl]
2026-08-22 Update README with DEMON_INDX requirement and BOM details
    Added a note about the requirement for DEMON_INDX macros and updated the BOM section with MCU recommendations.
2026-08-24 Small updates & tweaks, added a start tool check
    [DEMON_INDX_EXTRAS.cfg, indx-tc-macros.cfg, indx.cfg]
2026-08-25 Change default value of restore_z parameter
    [indx-tc-macros.cfg]
2026-08-26 Add tool change behavior settings in indx.cfg
    Added configuration options for tool change behavior, including parking location and nozzle cleaning settings.
    [indx.cfg]
2026-08-26 Add valid_restore variable and improve tool change logic
    Added variable_valid_restore to manage restoration state during tool changes. Enhanced gcode macros for tool position checks and exit behavior.
    [indx-tc-macros.cfg]
2026-08-27 Fix condition for dock_dir in indx-tc-macros.cfg
    [indx-tc-macros.cfg]
2026-08-27 Refactor tool change macros for clarity and efficiency
    [indx-tc-macros.cfg]
2026-08-28 Fix G-code commands for toolhead movement
    [indx-tc-macros.cfg]
2026-08-29 Remove unused driver_vars from homing configuration
    Removed unnecessary driver_vars variable assignments from homing macros.
    [DEMON_INDX_HOMING.cfg]
2026-08-29 Fix run current messages in DEMON_INDX_HOMING.cfg
    [DEMON_INDX_HOMING.cfg]
2026-08-29 Update config file references from settings to config
    [DEMON_INDX_HOMING.cfg]
2026-09-05 Update G-code for filament change and pause
2026-09-10 Clean up blank lines in indx-cal.cfg
    Removed unnecessary blank lines in G-code macros.
    [indx-cal.cfg]
